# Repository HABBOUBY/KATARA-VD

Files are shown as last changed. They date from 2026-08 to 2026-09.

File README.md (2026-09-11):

<div align="center">

# KATARA-VD

### une mahcine qui ne vend pas mais elle donne

<p align="center">
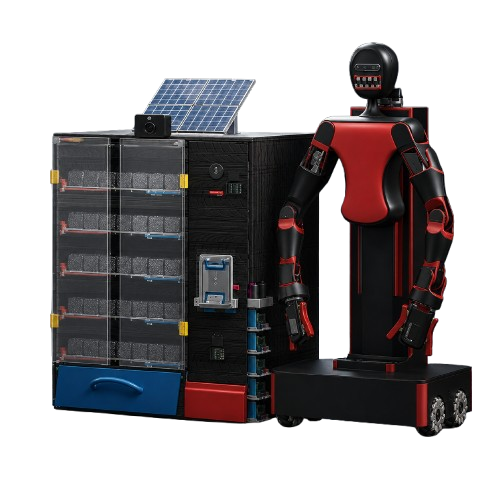
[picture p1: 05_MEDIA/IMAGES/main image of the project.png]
  
</p>

<p align="center">
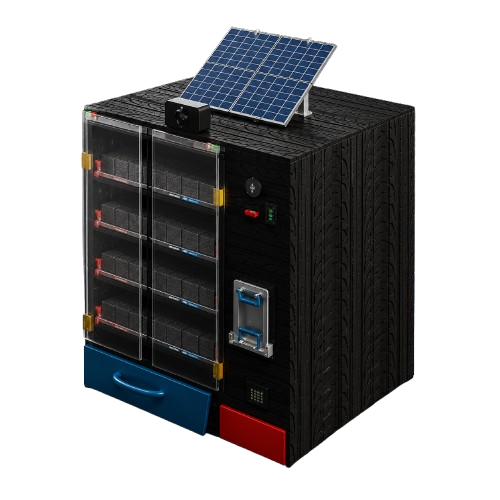
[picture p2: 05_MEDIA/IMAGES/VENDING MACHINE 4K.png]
  
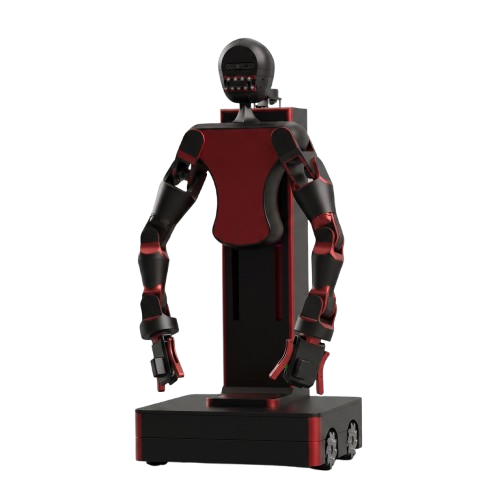
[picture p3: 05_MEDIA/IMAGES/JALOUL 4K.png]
  
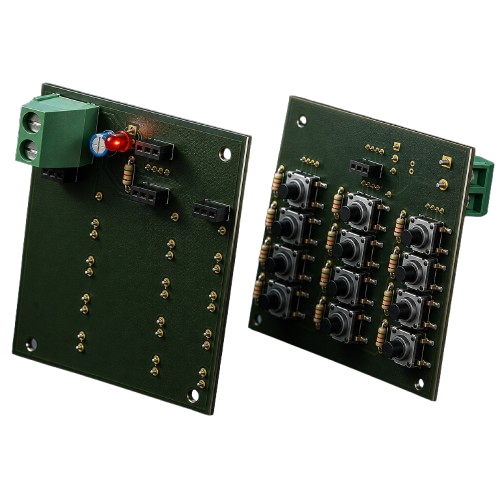
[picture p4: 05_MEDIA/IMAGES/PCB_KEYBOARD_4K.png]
  
</p>










Built by **HABBOUBY EDEM**

</div>

---

## Table of Contents

- [About](#about)
- [Repository Structure](#repository-structure)
- [Scope of This Submission](#scope-of-this-submission)
- [Note on Physical Fabrication](#note-on-physical-fabrication)
- [The Story Behind KATARA-VD](#the-story-behind-katara-vd)
- [The Ecosystem: 2 Systems, 1 Mission](#the-ecosystem-2-systems-1-mission)
- [Vending Machine](#vending-machine)
  - [Part 1 — Skeleton, Shelving & Archimedean Dispensers](#part-1--skeleton-shelving--archimedean-dispensers)
  - [Part 2 — Solar Power & Access Doors](#part-2--solar-power--access-doors)
  - [Part 3 — Prescription Verification System](#part-3--prescription-verification-system)
  - [Part 4 — Coin Dispensing Mechanism ("Giving Money")](#part-4--coin-dispensing-mechanism-giving-money)
  - [Part 5 — Coin Acceptance & Storage](#part-5--coin-acceptance--storage)
  - [Part 6 — Charity Keypad PCB](#part-6--charity-keypad-pcb)
  - [Part 7 — Thermal Sensing & Voice Interaction](#part-7--thermal-sensing--voice-interaction)
- [JALOUL — The Restocking Humanoid](#jaloul--the-restocking-humanoid)
  - [Part 8 — Head & Expression System](#part-8--head--expression-system)
  - [Part 9 — Body & Shoulder Joints](#part-9--body--shoulder-joints)
  - [Part 10 — Arm Completion & 360° Gripper](#part-10--arm-completion--360-gripper)
  - [Part 11 — Mecanum Base & Vertical Lift](#part-11--mecanum-base--vertical-lift)
  - [Part 12 — Frame Reinforcement & LiDAR](#part-12--frame-reinforcement--lidar)
- [The Humanitarian Logic — How the Community Fund Works](#the-humanitarian-logic--how-the-community-fund-works)
- [Electronics & PCB](#electronics--pcb)
- [Materials & Fabrication](#materials--fabrication)
- [Fasteners](#fasteners)
- [CAD Files](#cad-files)
- [Simulations](#simulations)
- [On AI Assistance](#on-ai-assistance)
- [Future Improvements](#future-improvements)
- [License](#license)

---

## About

**Katara-vd** une machine intelligente qui donne au lieu de vendre les médiacaments pour les personnes qui ont besoin . et pour que les riches personnes ont accès à cette mahicne ils doivent payer 2 euro , accompagné d'un huamnoid robot qui permet de remplir le distributeur .

Katara-vd  est le projet principal constitué de deux mini -projet:

-le distributeur: qui a une partie pour les médicaments , de plus , ce distributeur a une partie pour les dons qui a un mécanisme de pousse pour donner de l'argent et une petite pièce pour trier les pièces de monnaie ( seulement accepte les pièces de 2 euro)

-The humanoid robot  , son nom est "JALLUL " son tache est de remplir le distributeur lorsqu'il est vide de médicament 

---

## Repository Structure

```text
KATARA-VD/
│
├── 01_3D/
│   ├── SOLIDWORKS_FILES/
│   │   ├── HUMANOID_ROBOT JALOUL/      
│   │   └── VENDING_MACHINE/            
│   ├── STEP_FILES/
│   │   ├── HUMANOID_ROBOT JALOUL/      
│   │   └── VENDING_MACHINE/         
│   └── STL/
│       ├── HUMANOID_ROBOT JALOUL/      
│       └── VENDING_MACHINE/            
│
├── 02_DXF/
│   └── VENDING_MACHINE/
│
├── 03_PCB_DESIGN/
│   ├── VENDING MACHINE PCB.kicad_sch / .kicad_pcb / .kicad_pro / .kicad_prl
│   └── CARTE ELEC MEC 07.step
│
├── 04_DOCS/
│   └── KATARA-VD_PCB_Components.xlsx   
│   └──WIRING
|
├── 05_MEDIA/
│   ├── IMAGES/
│   │   ├── main image of the project.png
│   │   ├── VENDING MACHINE 4K.png
│   │   ├── JALOUL 4K.png
│   │   ├── JALOUL in different positions.png
│   │   └── PCB_KEYBOARD_4K.png
│   └── SIMULATIONS/
│       ├── mechanism of prescription.gif
│       ├── mechanism of giving money.gif
│       ├── GIF MEC PUSHING THE MONEY INTO THE BOX.gif
│       ├── mechanism for opening and closing door.gif
│       └── translation of the robot on yy' axis.gif
│
├── LICENSE
└── README.md
```

---

## remarque pour la fabrication physique 

malheuresemnt j'ai pas accès à l'impression 3d  pour faire un petit prototype et les composants électriques car ils osnt très chères ( raspberry pi 5 and intel real sense)

Mais "KATARA" est pret pour la mettre en production réelle et le rendre fonctionel ( j'ai mis tous les dossiers nécessaires pour l'impression  3d et le découpe cnc)

- **CNC laser-cut MDF** (`02_DXF/`) 
- **3D-printable STL/STEP** (`01_3D/`) 

-une petite remarque: j'ai fait ce mixage de matière  car il y a des pièces qui sont un peu grande donc il est impossible de l'imprimer avec une printer 3D local

---

## Comment l'idée de KATARA est née
Cette idée est née du hackclub comme il est  "charitable " club , donc j'ai pensé à faire une chose qui a des bienfaits pour tous le monde .

---

# Le distributeur 

## Partie 1 : MEC CiSEAUX

<p align="center">
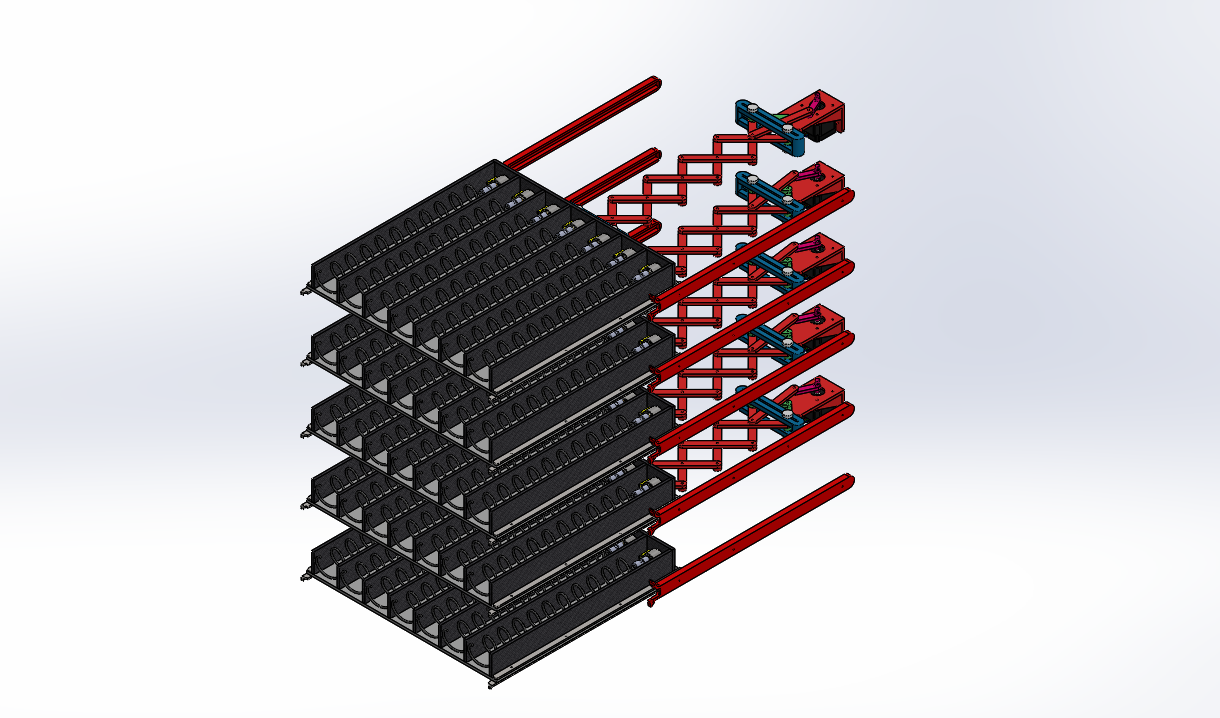
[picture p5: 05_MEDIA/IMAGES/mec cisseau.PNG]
  
</p>

Le distributeur a  5 principaux plateaux qui referment les médicaments .Donc pour que les plateaux soient accessibles à "JALOUL"  , doit avoir un mvt en translation donc le mec de ciseux permet les plateaux de sortir autrement dit mec ciseaux permet de  l'étirement et le raccourcissement des plateaux.Ce mec ciseaux est accompagné avec un stepper A17 de telle façon le mvt en rotation se transforme en translation

---

## Partie 2- panneau solaire et le porte intelligent 

<p align="center">
  
</p>

AU cas ou les batteries sont vide , et n'existe pas du courant donc il le panneau solaire est un alternatif dans ce cas ( qui permet de charger un batterie et cette batterie va etre consommé au cas ou les batteries vides.
De plus , ce distributeur a une porte intelligente qui s'ouvre et se ferme avec deux vérins électriques d'un façon  à transformer le mvt linéaire en mvt rotatif .Et ça a une dualité de fonction le distributeur n'est pas accessibles aux personnes seulement au "JALLOUL"

---

## Part 3 — Scanner et vérifier l'accès pour les médicaments
<p align="center">
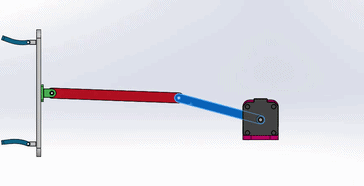
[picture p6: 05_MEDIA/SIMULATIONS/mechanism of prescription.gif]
  
</p>

Pour avoir un accès légal pour le distributeur , doit etre la personne accompagné avec une ordonnance.Cette etapge est guidé avec un mécanisme linéaire avec un stepper nema A 17 qui permet de translater un support qui a intérieument deux aimants magnétiques de telle façon l'ordonnace est attaché au support avec deux fixation que peut la personnes l'ouvrir et le fermer  ( aussi ces deux fixations ont à son intérieur un aimant magnétique de façon une attraction magnétique va etre crée avec le support principal ).Puis un caméra intelreal sense va détecter  le nom du médicament .Et finalement le médicament est poussé avec un spirale ( avec un moteur pas à pas petit ) puis il tombe en faisant une chute libre.

<p align="center">
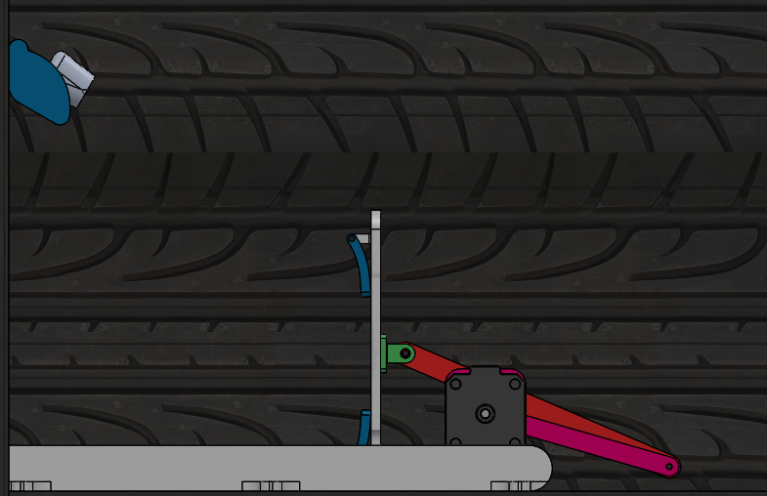
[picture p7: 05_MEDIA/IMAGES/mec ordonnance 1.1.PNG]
  
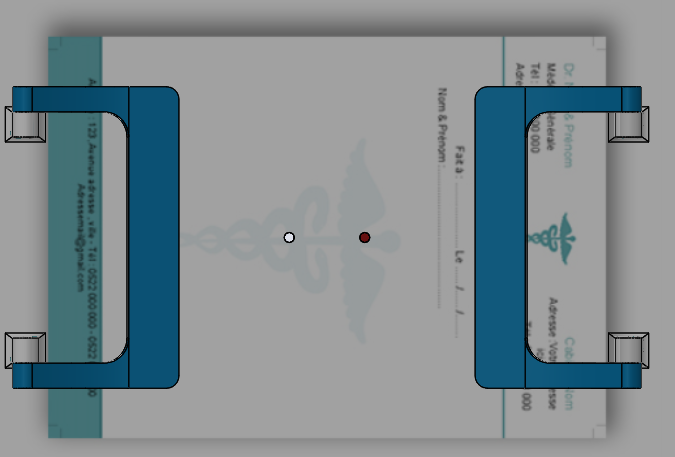
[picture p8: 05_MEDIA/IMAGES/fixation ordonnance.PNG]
  
</p>

*A gauche: le mvt linéaire par le stepper et le scan avec le caméra intelreal sense * 
*A droit : le support de l'ordonnance et ses deux fixations  qui vont  l'attatacher *

---

## Part 4 — système de pousse de l'argent

<p align="center">
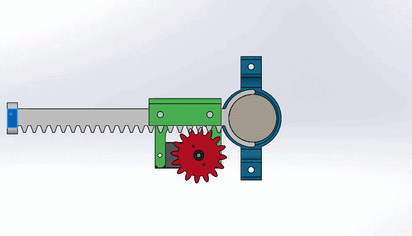
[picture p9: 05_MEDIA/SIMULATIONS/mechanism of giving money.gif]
  
</p>
<p align="center">
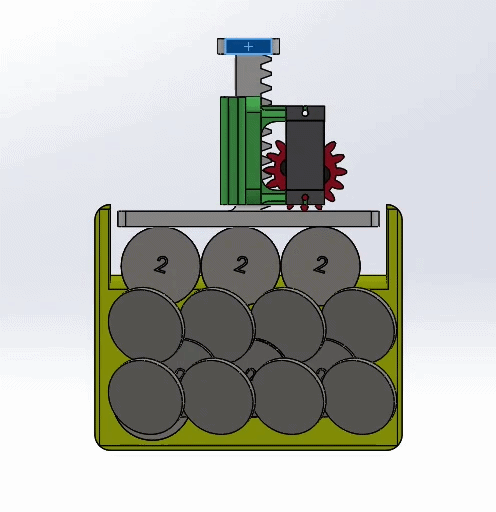
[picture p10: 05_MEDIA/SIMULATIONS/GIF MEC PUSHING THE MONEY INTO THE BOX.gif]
  
</p>

Le premier GIF  montre , le pousse de l'argent pour les donnés aux personnes qui ont besoin 
Le dexième GIF montre aussi le pousse de l'argent mais dans un box , et ce mec est pour conserver les pièces de monnaies que les riches personnes ont donné  dans le boxe  qui sont tombé de la pièce de tri de monnaie 

---

## Part 5 — LA pièce de tri de l'argent 

<p align="center">
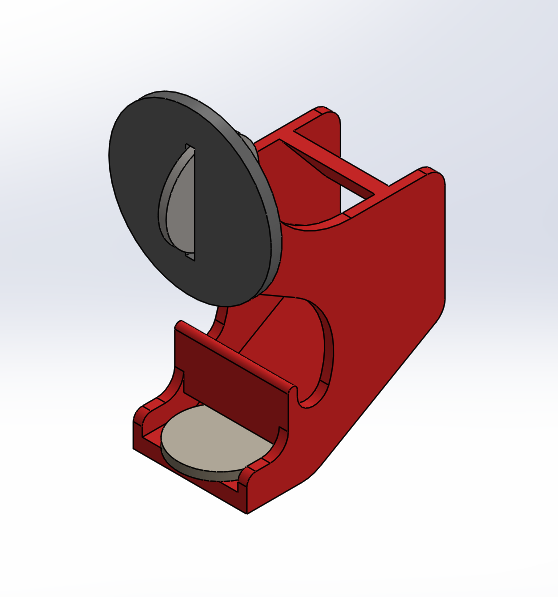
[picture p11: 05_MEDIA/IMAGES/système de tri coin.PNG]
  
</p>

la pièce de monnaie se glisse d'un façon cette pièce permet de trier les pièces , donc comment ??
Cette pièce a un petit mur qui est oblique d'un 30 degré puis il est suivi  d'un trou  de diamètre un peu plus petit du pièce de monnaie du 2 euro donc si la pièce donné est 2euro va etre glissé  et se tombe dans le box  et il y a un capteur IR qui va détcteer qu'elle a tombé.
Si la pièce est plus petite que 2 euro donc elle va tomber au trou et sort et si elle est plus  grande que 2 euro au début il ne peut pas entrer à cette pièce

regardez l'imagez pour mieux comprendre

---

## Part 6 Clavier PCB pour l'identfication

<p align="center">
  
</p>
Chaque personne de la ville ou cette machine est placé a un code  spécifique à lui  , de telle façon le lorsque la personne entre son code il le connait (est ce qu'il a pris 2 euro par jours ou non ? ) ET il y a deux clavier pour les personnes qui ont besoin et son etat financière est  un peu faible et entre les personnes riches . une petite remarque : il existe deux  clavier un peu les dons et un pour les demandes et chaque clavier a aussi un ecran oled
De plus , j'ai fait une petite liste qui renferme tous les composants électriques nécessaires pour réaliser ces claviers

---

## Part 7 — Détection thermique et interaction vocale

Une caméra  infrarouge qui permet de détecter des signes que quelque chose ne va pas de la tristesse ou un état physique  qui demande  une urgence médicale. avec un petit "speaker" intégré qui va répéter des morceaux mp3 pour faire une interaction avec les personnes et le rendre plus dynamique .

---

# JALOUL — the huamnoid robot

## Part 8 — Head & Expression System

<p align="center">
  
</p>

la tête du jaloul a un caméra Intel Realsense pour détecter le trajectoire et l'entrainer sur le remplissage du distributeur et lorsqu'il est vide 
et aussi les places exactes à mettre les médicaments.
Aussi jalloul a une bouche mécanique pour le rendre un peu plus réel accompagné avec un sevro moteur MG95
( the metal gear)
A l'intérieur de sa tête il y a raspberry pi 5 pour l'analyse de données et faire bouger aussi la bouche 

---

## Part 9 — Le corps et les articulations du "Jaloul"

"Jaloul" a 12 articulations ( 6 articulations pour chaque main)

la première articulation est dans l'épaule .Puis la bras supérieur à une articulation de façon que l'axe du chaque articulation est orthogonal  à l'autre.Puis une articulation pour le coude et finalement un pour le poignet et une autre pour les doigts .

ces articulations sont suffisantes pour faire les tâches nécessaires 

### le box du médicament 
<p align="center">
  medication-tray-isometric-view png
  medication-tray-spacing-topview png
</p>

puisque "JALOUL" a un gripper qui ne peut pas entrer  entre les boxes du médicament  , de telle façon j'ai on va mettre les médicaments espacés pour que jalloul peut les porter avec ses deux "gripper"

## Part 11 — le mvt vertical du jaloul

<p align="center">
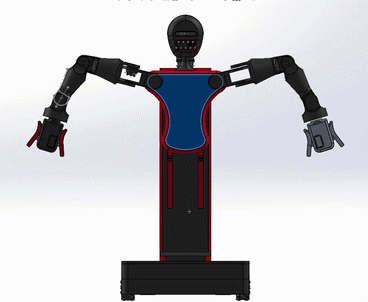
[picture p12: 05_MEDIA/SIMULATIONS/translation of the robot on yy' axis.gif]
  
</p>
jaloul  a un mvt vertical grace à un système vis et écrous pour le donner l'accès au tous éatges du distributeur 
ce mvt lineàire est dû à un mvt rotatif d'un moteur stepper nema A17  avec un  accouplement entre le vis et l'axe du moteur ( juste je vais ajouter un petit remarque que le guidage de vis est accompagné avec un roulement à billes radiales en haut )

aussi jalloul a un capteur lidar qui le permet de tracer son trajectoire et détecter aussi les obstacles pour un mieux mvt

de plus jaloul a une base de 4 roues mecanum qui le donne des choix dans mvt comme ça(↑↓←→ )

---

## Electronics & PCB

- **Raspberry Pi 5** — analyse de données
- 
- **Arduino Mega 2560** —carte de commande 
- **Custom KiCad PCB** - le clavier qui permet de connaître chacun avec son identifiant 

voire les composants électriques d'amazon: 
[`04_DOCS/KATARA-VD_PCB_Components.xlsx`](04_DOCS/KATARA-VD_PCB_Components.xlsx).

---

## Materials & Fabrication

| Part type | Material | Fabrication |
|---|---|---|
| Large flat panels (walls, base, shelves) | MDF | CNC laser cutting (`02_DXF/`) |
| Mechanisms & structural parts | ABS | FDM 3D printing |
| Covers & lightweight parts | PLA | FDM 3D printing |

| Setting | Value |
|---|---|
| Layer Height | 0.20 mm |
| Nozzle | 0.4 mm |
| Infill | 20% |
| Walls | 3 |
| Supports | Only where needed |

---

## Fasteners

| Screw | Length | Quantity |
|---|---:|---:|
| M3 | 20 mm | 40 |
| M3 | 30 mm | 40 |

---

## Simulations

<table>
<tr>
<td width="33%" align="center">

**Prescription mechanism**



Rotary-to-linear extension that presents the prescription to the RealSense camera.

</td>
<td width="33%" align="center">

**Giving money mechanism**



Rack-and-pinion coin ejection, sized to a 1-euro coin.

</td>
<td width="33%" align="center">

**Coin storage**



Donated coins pushed securely into the storage box.

</td>
</tr>
<tr>
<td width="33%" align="center">

**Door actuation**

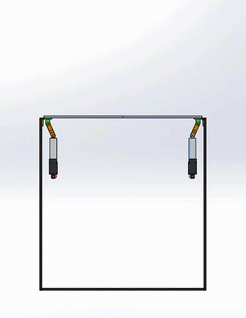
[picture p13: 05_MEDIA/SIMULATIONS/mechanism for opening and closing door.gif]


Dual-actuator, hinge-guided access doors.

</td>
<td width="33%" align="center">

**JALOUL — Y-axis translation**



The backpack lift traveling along the Y-Y′ axis via lead screw.

</td>
<td width="33%" align="center">

**JALOUL — arm reach**

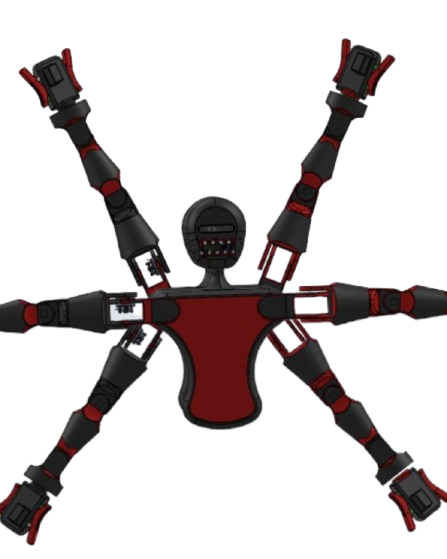
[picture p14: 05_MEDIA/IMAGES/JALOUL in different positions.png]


Both arms swept across multiple positions, showing the range unlocked by the extra joints.

</td>
</tr>
</table>

---

##ce que je peux faire dans le future 

-Faire un assemblage et imprimer les pièces  pour faire un petit prototype 
-ajoutez un drone pour transporter les médicaments du l'usine lorsque le stockage est vide

---

## License

**MIT License**.

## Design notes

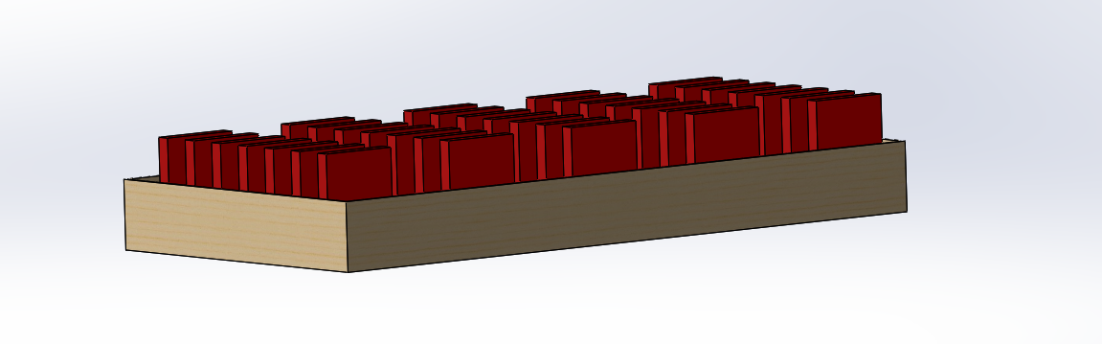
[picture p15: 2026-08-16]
05_MEDIA/IMAGES/medication-tray-isometric-view.png.PNG

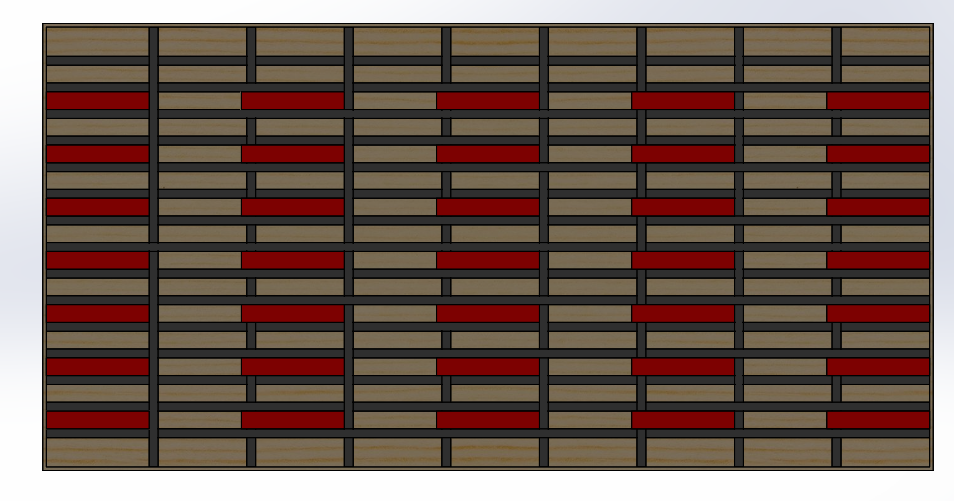
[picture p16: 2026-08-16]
05_MEDIA/IMAGES/medication-tray-spacing-topview.png.PNG

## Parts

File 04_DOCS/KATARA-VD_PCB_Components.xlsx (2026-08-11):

KATARA-VD — PCB Electronic Components (Keypad / Charity Module)
Component list for the charity keypad PCB — quantities, specs, and Amazon sourcing links
N° | Component | Quantity | Characteristics / Value | Remarks | Amazon Link | Unit
1 | Push Button (Tactile Switch) | 12 | 6x6mm, 4-pin THT, momentary SPST | Used for the keypad digits/entries on the charity donation interface. | View on Amazon (https://www.amazon.com/6x6mm-Tactile-Button-Micro-Switch/dp/B0F7FPCMCF) | pcs
2 | Resistor (Pull-down, for push buttons) | 12 | 10 kΩ, 1/4W, ±1% metal film | One per push button, used as pull-down/pull-up resistor on each digital input pin. | View on Amazon (https://www.amazon.com/Resistor-Resistors-Assortment-Breadboard-Electronics/dp/B0F4P352BB) | pcs
3 | Pin Socket Header (4-pin) | 5 | 2.54mm pitch, single row, 4-position female header | 5 separate 4-pin blocks — used as connectors/expansion headers on the PCB. | View on Amazon (https://www.amazon.com/Female-Headers-2-54mm-Single-Connector/dp/B08T5S54C5) | blocks
4 | Screw Terminal Block (01x02) | 1 | 2-pin, 5.08mm pitch, PCB mount | Power/signal input connector for external wiring. | View on Amazon (https://www.amazon.com/Terminal-Arduino-Electronics-Industrial-Control/dp/B0GMHFBW34) | pcs
5 | Capacitor (Decoupling) | 1 | 100 nF (0.1 µF), ceramic disc | Decoupling/filtering capacitor near the microcontroller supply pins. | View on Amazon (https://www.amazon.com/100PCS-100nf-Ceramic-Capacitor-Capacitors/dp/B0H6MJXNKM) | pcs
6 | Resistor (LED current-limiting) | 1 | 220 Ω, 1/4W | Current-limiting resistor in series with the OLED status LED / indicator. | View on Amazon (https://www.amazon.com/Resistor-Resistors-Assortment-Breadboard-Electronics/dp/B0F4P352BB) | pcs
7 | LED | 1 | 5mm, standard round, THT | Status/indicator LED for the charity keypad module. | View on Amazon (https://www.amazon.com/Diffused-Lighting-Electronics-Components-Emitting/dp/B01C3ZZT2I) | pcs
 | TOTAL COMPONENTS | 33
Note: Resistor values (10 kΩ pull-down, 220 Ω current-limiting) are recommended standard values — adjust based on final PCB testing and MCU logic level (3.3V/5V).
Links point to representative Amazon listings for sourcing reference; verify specs/pricing before ordering.

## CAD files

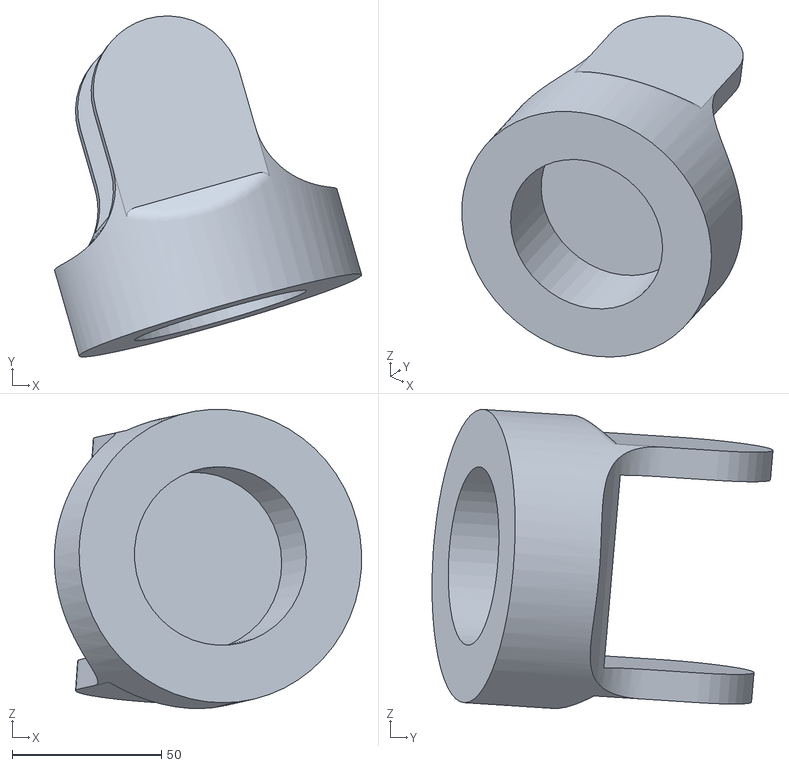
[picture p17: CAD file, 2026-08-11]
01_3D/STL/HUMANOID_ROBOT JALOUL/total assembly of jaloul - assemblt jaloul main two-1 link 4-1.STL
103.0 x 114.4 x 100.3

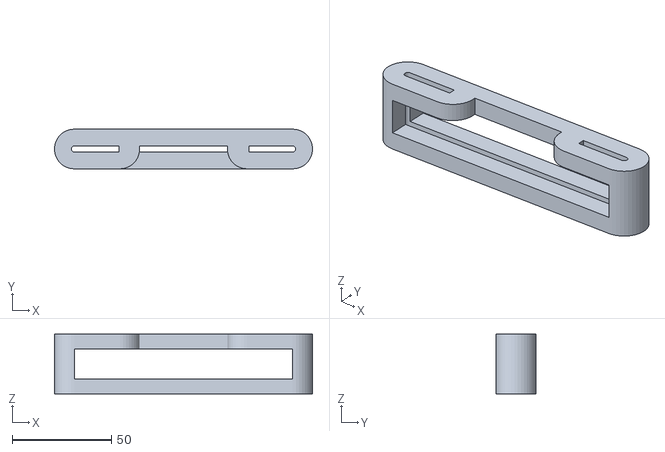
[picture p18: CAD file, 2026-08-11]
01_3D/STL/VENDING_MACHINE/assembly mec cisseau - guidage cisseau-1.STL
129.9 x 20.0 x 30.0

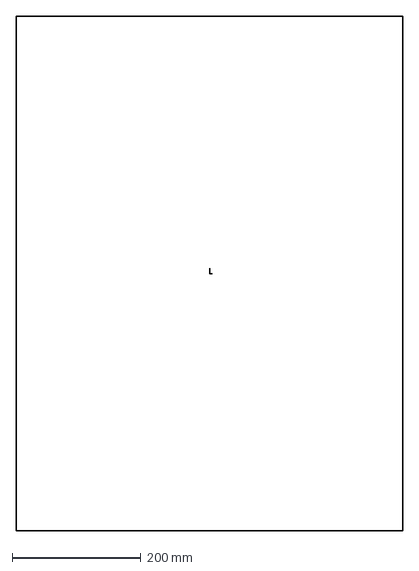
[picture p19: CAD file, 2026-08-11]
02_DXF/VENDING_MACHINE/mur vending machine main one.DXF
600.0 x 800.0 mm

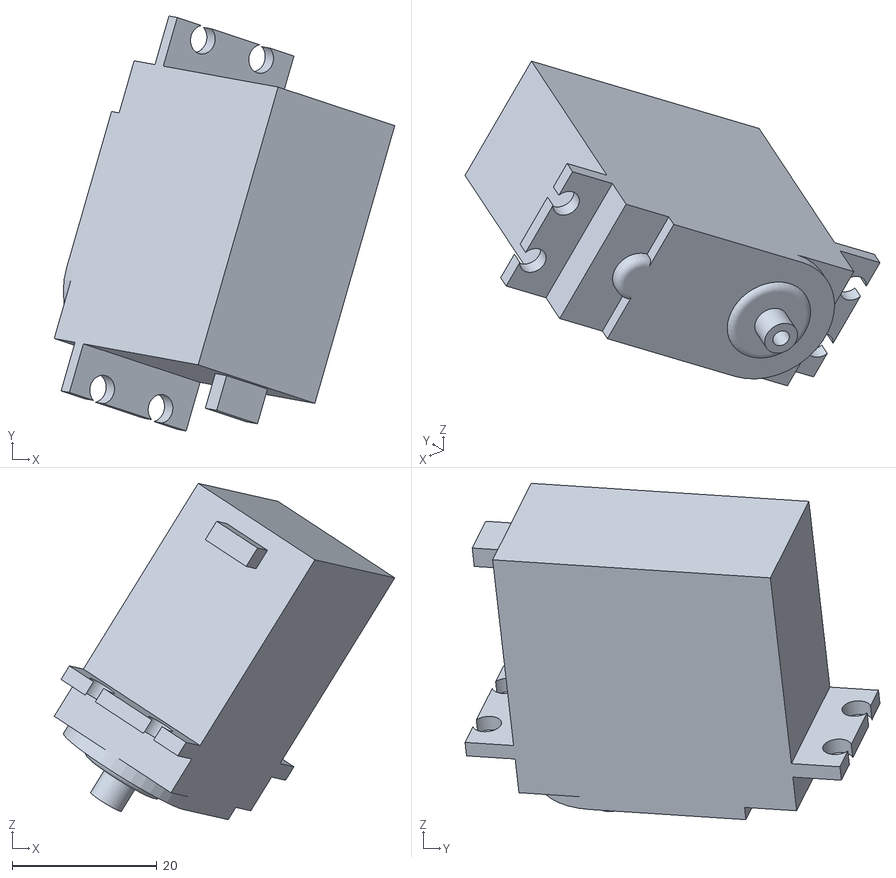
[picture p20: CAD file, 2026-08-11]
01_3D/STL/HUMANOID_ROBOT JALOUL/total assembly of jaloul - assemblt jaloul main two-1 Symétrieassembly gripper jalloul-3 Symétrieservo Assem-1 Symétrieservo strong junk 2-1.STL
47.1 x 57.3 x 46.5

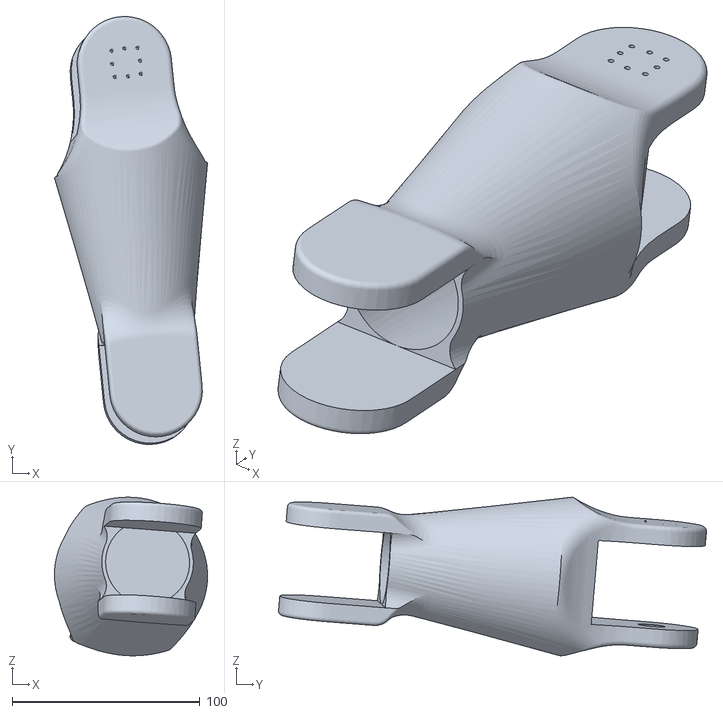
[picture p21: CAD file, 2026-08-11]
01_3D/STL/HUMANOID_ROBOT JALOUL/total assembly of jaloul - assemblt jaloul main two-1 LINK 3 JALOUL-1.STL
81.6 x 228.1 x 84.5

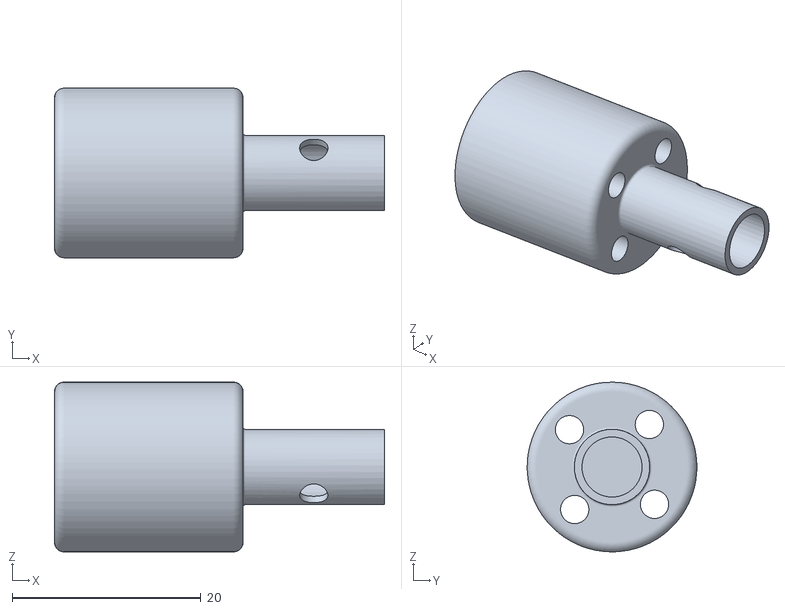
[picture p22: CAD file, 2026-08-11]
01_3D/STL/HUMANOID_ROBOT JALOUL/total assembly of jaloul - assembly bas robot jlayla-1 accouplement stpper with mecanum wheel-1.STL
35.0 x 18.0 x 18.0

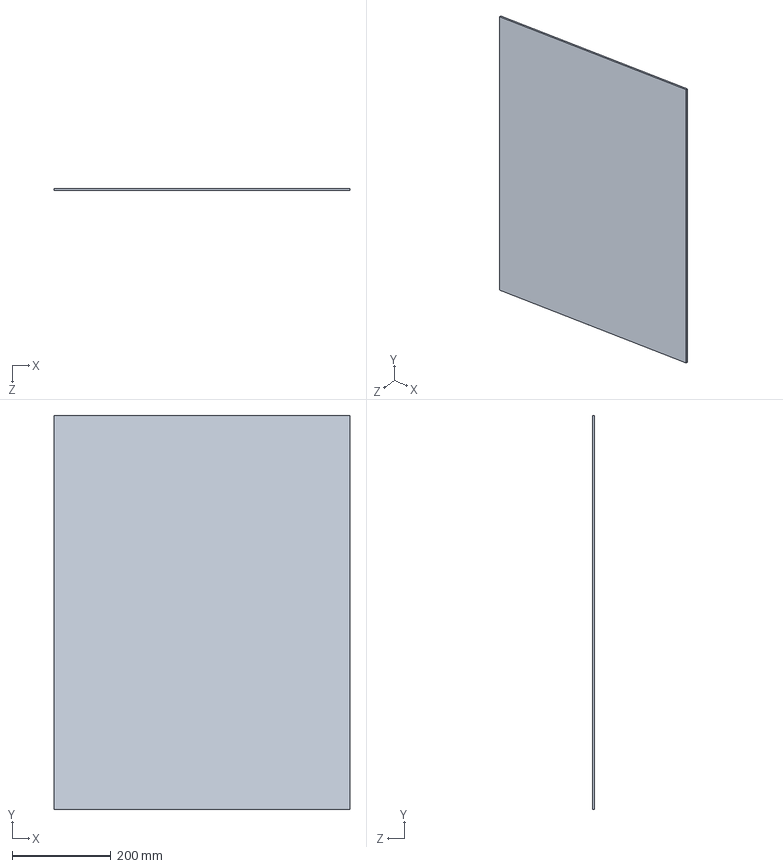
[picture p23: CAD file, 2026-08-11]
01_3D/SOLIDWORKS_FILES/VENDING_MACHINE/mur vending machine main one.SLDPRT
600.0 x 800.0 x 5.00 mm

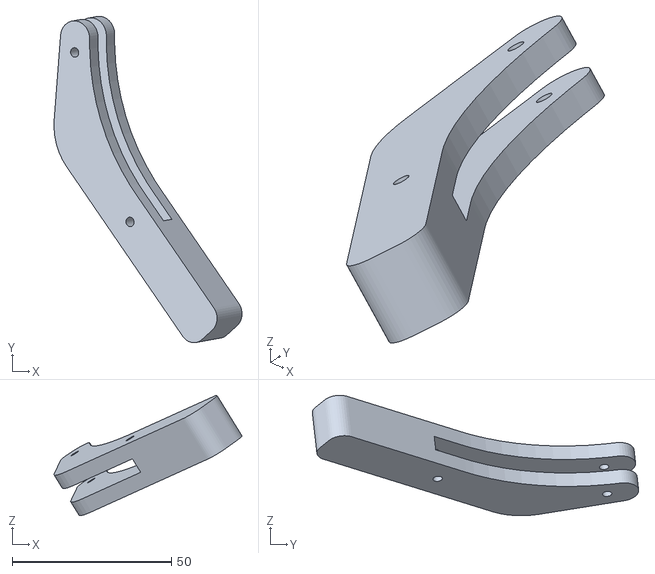
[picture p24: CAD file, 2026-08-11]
01_3D/STL/HUMANOID_ROBOT JALOUL/total assembly of jaloul - assemblt jaloul main two-1 assembly gripper jalloul-1 yed jaloul-1.STL
59.1 x 102.6 x 37.8

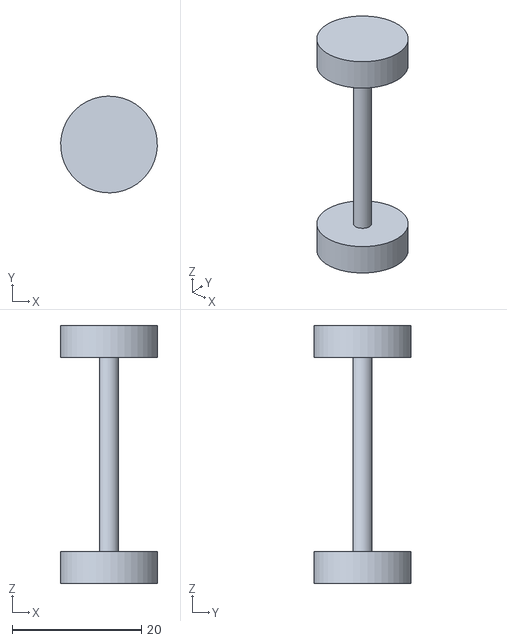
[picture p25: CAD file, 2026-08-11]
01_3D/STL/VENDING_MACHINE/assembly mec cisseau - roue guidage-1.STL
15.0 x 15.0 x 40.0

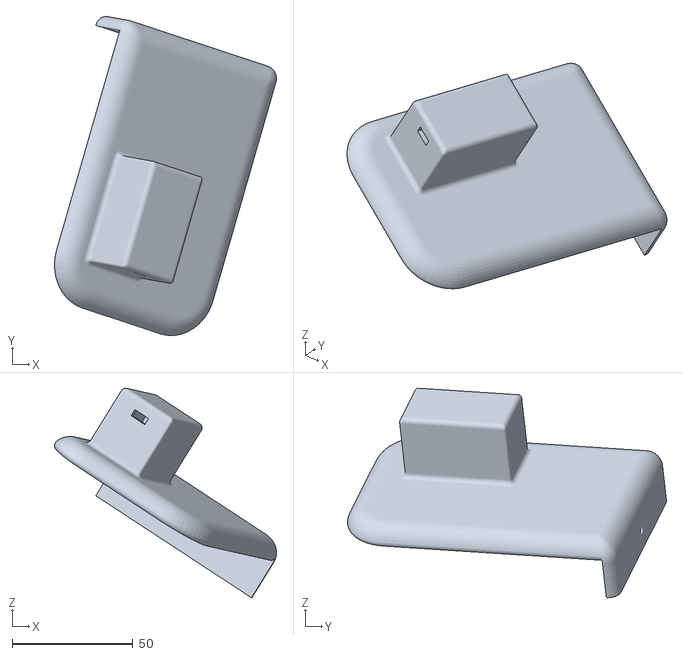
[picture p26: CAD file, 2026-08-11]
01_3D/STL/HUMANOID_ROBOT JALOUL/total assembly of jaloul - assemblt jaloul main two-1 Symétrieassembly gripper jalloul-3 SymétrieBASE GRIPPER JALLOUL-1.STL
92.0 x 132.2 x 86.8

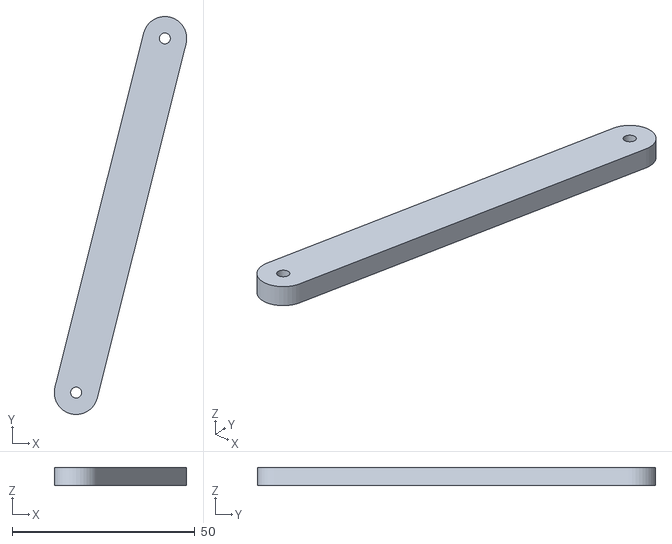
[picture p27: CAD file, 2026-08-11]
01_3D/STL/VENDING_MACHINE/assembly mec cisseau - bras motrice bdiha maak hheeeh-1.STL
36.3 x 109.0 x 5.00

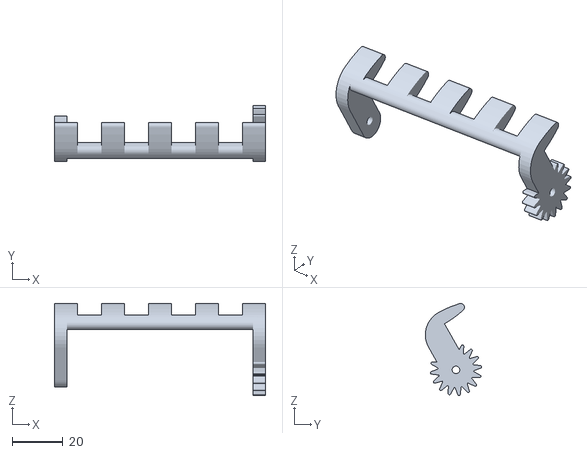
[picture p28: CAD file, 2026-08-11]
01_3D/STL/HUMANOID_ROBOT JALOUL/total assembly of jaloul - assemblt jaloul main two-1 assembly head of jaloul-1 dents du jaloul-1.STL
83.0 x 22.2 x 36.2

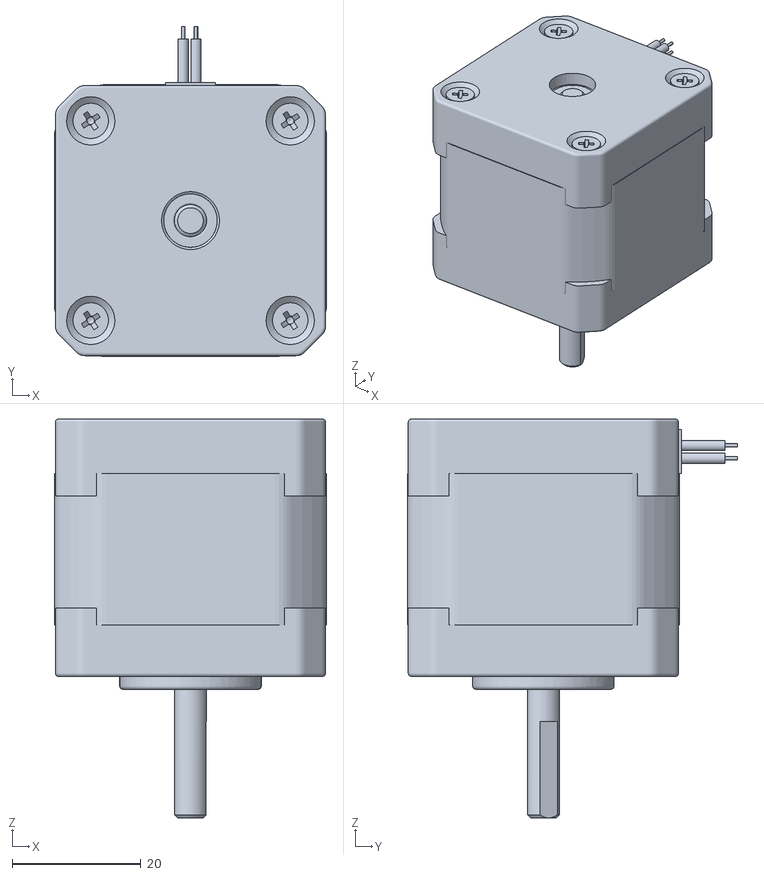
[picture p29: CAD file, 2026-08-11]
01_3D/STL/VENDING_MACHINE/assembly mec cisseau - 17HM15-0904S-1.STL
42.3 x 51.4 x 62.0

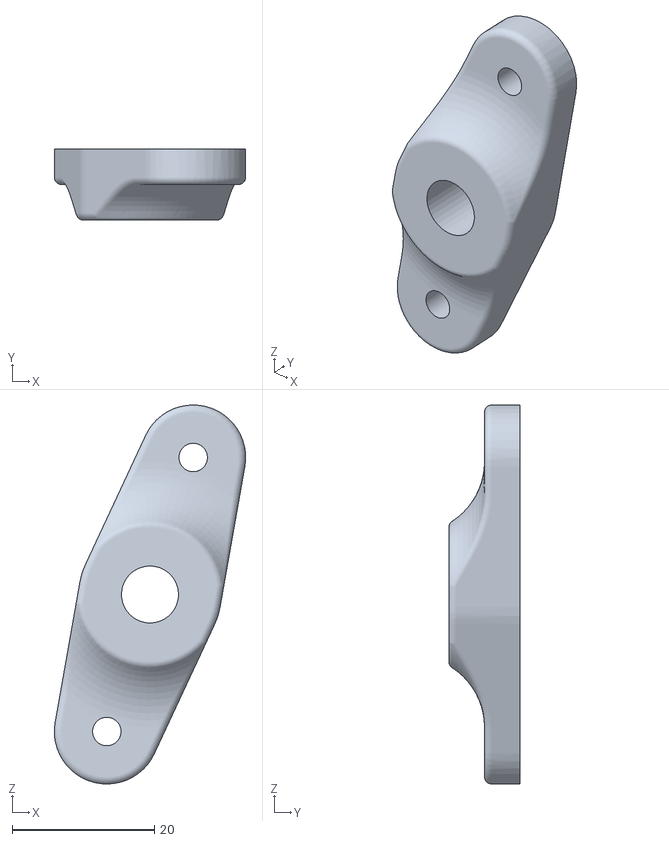
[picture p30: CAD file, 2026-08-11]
01_3D/STL/HUMANOID_ROBOT JALOUL/total assembly of jaloul - pièce de fixation-3.STL
26.9 x 10.0 x 53.2

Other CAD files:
01_3D/STL/VENDING_MACHINE/assembly mec cisseau - bras mère mec cisseau-6.STL
01_3D/STL/HUMANOID_ROBOT JALOUL/total assembly of jaloul - assemblt jaloul main two-1 assembly gripper jalloul-1 Symétriepignon jlayla-3.STL
01_3D/STL/VENDING_MACHINE/assembly mec cisseau - bras mère mec cisseau-1.STL
01_3D/STL/HUMANOID_ROBOT JALOUL/total assembly of jaloul - assemblt jaloul main two-1 assembly head of jaloul-1 M90S_ali.step-1 etiquette.step-1.STL
01_3D/SOLIDWORKS_FILES/HUMANOID_ROBOT JALOUL/BASE GRIPPER JALLOUL.SLDPRT
01_3D/SOLIDWORKS_FILES/HUMANOID_ROBOT JALOUL/BASE ROBOT JALOUL.SLDPRT
01_3D/SOLIDWORKS_FILES/HUMANOID_ROBOT JALOUL/LINK 3 JALOUL.SLDPRT
01_3D/SOLIDWORKS_FILES/HUMANOID_ROBOT JALOUL/LMH8UU.SLDPRT
01_3D/SOLIDWORKS_FILES/HUMANOID_ROBOT JALOUL/LeadScrew Nut 8mm x 2mmPitch.SLDPRT
01_3D/SOLIDWORKS_FILES/HUMANOID_ROBOT JALOUL/MG90S_arm01.step
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

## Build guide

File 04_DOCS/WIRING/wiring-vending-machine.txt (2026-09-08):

====================================================================
KATARA-VD — VENDING MACHINE — WIRING REFERENCE
====================================================================
No dedicated main PCB for this subsystem. The only custom PCB in the
whole project is the charity keypad module (see 03_PCB_DESIGN/).
Everything below lives on perforated prototyping boards , grouped by mechanism to keep wiring runs short.

--------------------------------------------------------------------
1. POWER SOURCES
--------------------------------------------------------------------
- 3x LiPo 3S (11.1V) packs
    -> main power rail for all DRV8825 drivers (VMOT) and actuators
- 1x solar storage battery
    -> charged by the rooftop solar panel
    -> feeds the 11.1V bus automatically whenever the LiPo packs run
       low (diode-OR / auto switch-over between LiPo and solar bank)
- 12V -> 5V buck regulators (mounted on the perfboards)
    -> supply the 5V logic rail: DRV8825 logic (VDD), OLED displays,
       IR sensor, PWM expansion boards, keypad PCB

--------------------------------------------------------------------
2. STEPPER DRIVERS — DRV8825 (41x TOTAL)
--------------------------------------------------------------------
Spread across several perfboards, one cluster per mechanism rather
than a single centralized board:

  - Scissor-lift steppers (NEMA 17)        -> 1x per shelf, 5 shelves
  - Archimedean-screw dispenser steppers   -> grouped per shelf
  - Prescription rotary-to-linear stepper  -> 1x
  - Remaining channels reserved / grouped per mechanism
    (see 04_DOCS/KATARA-VD_PCB_Components.xlsx for the full motor list)

Standard wiring per DRV8825 driver:
  VMOT           -> 11.1V rail (LiPo 3S / solar bank)
  GND (power)    -> common ground
  VDD            -> 5V logic rail
  GND (logic)    -> common ground
  STEP           -> Arduino Mega 2560 digital pin
  DIR            -> Arduino Mega 2560 digital pin
  ENABLE         -> tied low, unless a per-shelf disable line is added
  A1 / A2 / B1 / B2 -> stepper motor coil pairs
  Current limit  -> set via onboard potentiometer, per motor's rating

--------------------------------------------------------------------
3. RASPBERRY PI 5 — VISION & ANALYSIS (x2, ISOLATED SUPPLIES)
--------------------------------------------------------------------
Pi 5 #1 — Infrared & Interaction
  - MLX90640 thermal camera  -> I2C
  - Speaker (via amplifier)  -> I2S or analog audio out
  - Power: own isolated 5V/5A supply, regulated off the 11.1V rail

Pi 5 #2 — Prescription Analysis
  - Intel RealSense D435     -> USB 3.0
  - Power: own isolated 5V/5A supply, regulated off the 11.1V rail

Both Pi 5 boards send their decisions to the Arduino Mega 2560 over
serial/USB; the Mega handles all actuator/motor timing.

--------------------------------------------------------------------
4. SERVO CONTROL — PWM EXPANSION BOARDS (x3)
--------------------------------------------------------------------
3x 16-channel PWM expansion boards (PCA9685-type), addressed over I2C
from the Arduino Mega 2560:

  Board 1 -> Prescription arm servos + magnetic-mount servos
  Board 2 -> Coin dispensing (rack & pinion) + lock/unlock door servo
  Board 3 -> Door actuators (verins) + spare channels

Each board:
  VCC (logic)      -> 5V logic rail
  V+ (servo power) -> 5V logic rail (separate 5V servo rail if current
                       draw requires it)
  GND              -> common ground
  SDA / SCL        -> Arduino Mega 2560 I2C bus (unique address per
                       board via address pins)

--------------------------------------------------------------------
5. SENSORS & INTERFACE
--------------------------------------------------------------------
  - IR sensor (coin acceptance)   -> Arduino Mega 2560 digital input
  - Coin sorter mechanism         -> mechanical only, no electronics
  - OLED displays (x2, 1/keypad)  -> I2C, distinct addresses
  - Charity keypad PCB            -> button matrix to Mega digital
                                      inputs + OLED on shared I2C bus

--------------------------------------------------------------------
6. SOLAR / CHARGE PATH
--------------------------------------------------------------------
  Solar panel -> charge controller -> solar storage battery
              -> 11.1V bus (shared with the 3x LiPo 3S packs via
                 diode-OR / automatic switch-over)

--------------------------------------------------------------------
NOTES
--------------------------------------------------------------------
- No custom PCB for the main system: DRV8825 clusters and 12->5V
  regulators live on perfboards, grouped by mechanism.
- The only custom PCB is the charity keypad module (03_PCB_DESIGN/).
- Common ground must be shared across every perfboard, both Pi 5
  units, the Arduino Mega 2560, and the LiPo/solar power path.
- Exact pin assignments for the Arduino Mega 2560 are firmware-side
  and will be documented once control code is written (see README ->
  Future Improvements).

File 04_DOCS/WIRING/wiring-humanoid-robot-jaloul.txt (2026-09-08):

====================================================================
KATARA-VD — JALOUL (HUMANOID ROBOT) — WIRING REFERENCE
====================================================================
No dedicated PCB for JALOUL either. Same approach as the vending
machine: DRV8825 driver(s) and 5V regulation live on a perforated
prototyping board .

--------------------------------------------------------------------
1. POWER SOURCES
--------------------------------------------------------------------
- 2x LiPo 3S (11.1V) packs:
    Pack 1 -> Navigation systems (RPLiDAR, sensors, logic-side
              electronics)
    Pack 2 -> Joint actuation & Y-Y' translation system (all servos +
              all steppers: arms, gripper, mecanum base, backpack lift)
- Raspberry Pi 5:
    -> own dedicated, isolated power bank — never shares a rail with
       Pack 1 or Pack 2, to protect it from motor noise/brownouts
- 5V logic rail:
    -> regulated off Pack 2, feeds DRV8825 logic and low-power
       peripherals

--------------------------------------------------------------------
2. STEPPER DRIVERS — DRV8825, 5V LOGIC
--------------------------------------------------------------------
DRV8825 driver(s) for the NEMA 17 stepper(s), mounted on the perfboard:
  VMOT           -> 11.1V rail (Pack 2)
  GND (power)    -> common ground
  VDD            -> 5V logic rail
  GND (logic)    -> common ground
  STEP           -> control board digital pin
  DIR            -> control board digital pin
  A1 / A2 / B1 / B2 -> stepper coil pairs
  Current limit  -> set via onboard potentiometer

Note: the mecanum base (4x NEMA 23) and the Y-Y' backpack lift
(1x NEMA 23) run on their own higher-current drivers, wired the same
way but sized for NEMA 23 current draw — check
04_DOCS/KATARA-VD_PCB_Components.xlsx for driver ratings per motor.

--------------------------------------------------------------------
3. RASPBERRY PI 5 — VISION & NAVIGATION
--------------------------------------------------------------------
  - Intel RealSense D435 -> USB 3.0, head-mounted vision
  - RPLiDAR              -> USB/UART, obstacle detection & mapping
  - Power: dedicated power bank, isolated from Pack 1 and Pack 2
  - Sends motion/joint commands to the onboard control board over
    serial/USB

--------------------------------------------------------------------
4. SERVO CONTROL
--------------------------------------------------------------------
  - MG90S servos -> mouth mechanism + smaller joints
  - MG995 servos -> gripper, one per arm
  - Power: 5V logic rail (Pack 2), common ground with the control board

--------------------------------------------------------------------
5. POWER SPLIT LOGIC
--------------------------------------------------------------------
  Pack 1 (Navigation):    RPLiDAR + navigation sensors + logic
  Pack 2 (Joints & Y-Y'): all servos + all steppers (arms, gripper,
                           mecanum base, backpack lift)
  Pi 5 power bank:        isolated — never shares a rail with either
                           LiPo pack

--------------------------------------------------------------------
NOTES
--------------------------------------------------------------------
- No custom PCB for JALOUL: DRV8825 driver(s) and 5V regulation live
  on a perfboard, same approach as the vending machine.
- Common ground must be shared across the perfboard, the Raspberry
  Pi 5, and both LiPo packs — except where isolation is intentional
  (the Pi 5 power bank).
- NEMA 23 current draw (base + lift) is significantly higher than
  NEMA 17 — size wiring gauge and driver heatsinking accordingly.
- Exact control-board pin assignments are firmware-side and will be
  documented once control code is written (see README -> Future
  Improvements).

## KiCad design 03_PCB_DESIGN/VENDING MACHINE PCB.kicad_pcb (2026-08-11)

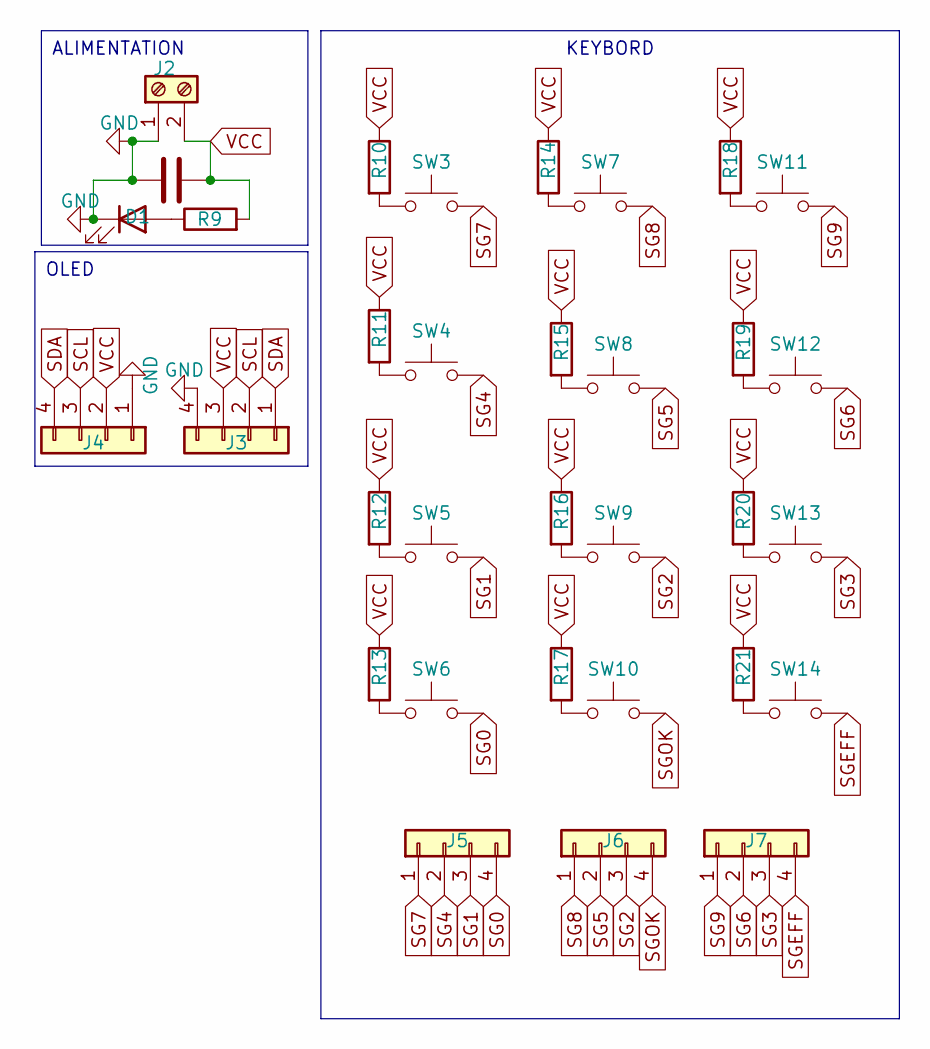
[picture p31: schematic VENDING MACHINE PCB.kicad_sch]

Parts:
C1: C; CP_Radial_D4.0mm_P1.50mm
D1: LED; LED_D3.0mm
J2: Screw_Terminal_01x02; TerminalBlock_Phoenix_MKDS-1,5-2_1x02_P5.00mm_Horizontal
J3, J4, J5, J6, J7: Conn_01x04; PinSocket_1x04_P1.27mm_Vertical
R9, R10, R11, R12, R13, R14, R15, R16, R17, R18, R19, R20, R21: R; R_Axial_DIN0204_L3.6mm_D1.6mm_P5.08mm_Horizontal
SW3, SW4, SW5, SW6, SW7, SW8, SW9, SW10, SW11, SW12, SW13, SW14: SW_Push; SW_Push_1P1T_NO_CK_KSC6xxG

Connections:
GND: C1.2, D1.1 (K), J2.1, J3.4, J4.1
unnamed: D1.2 (A), R9.1
unnamed: R10.2, SW3.1
unnamed: R11.2, SW4.1
unnamed: R12.2, SW5.1
unnamed: R13.2, SW6.1
unnamed: R14.2, SW7.1
unnamed: R15.2, SW8.1
unnamed: R16.2, SW9.1
unnamed: R17.2, SW10.1
unnamed: R18.2, SW11.1
unnamed: R19.2, SW12.1
unnamed: R20.2, SW13.1
unnamed: R21.2, SW14.1
SCL: J3.2, J4.3
SDA: J3.1, J4.4
SG0: J5.4, SW6.2
SG1: J5.3, SW5.2
SG2: J6.3, SW9.2
SG3: J7.3, SW13.2
SG4: J5.2, SW4.2
SG5: J6.2, SW8.2
SG6: J7.2, SW12.2
SG7: J5.1, SW3.2
SG8: J6.1, SW7.2
SG9: J7.1, SW11.2
SGEFF: J7.4, SW14.2
SGOK: J6.4, SW10.2
VCC: C1.1, J2.2, J3.3, J4.2, R9.2, R10.1, R11.1, R12.1, R13.1, R14.1, R15.1, R16.1, R17.1, R18.1, R19.1, R20.1, R21.1

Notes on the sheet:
ALIMENTATION
KEYBORD
OLED

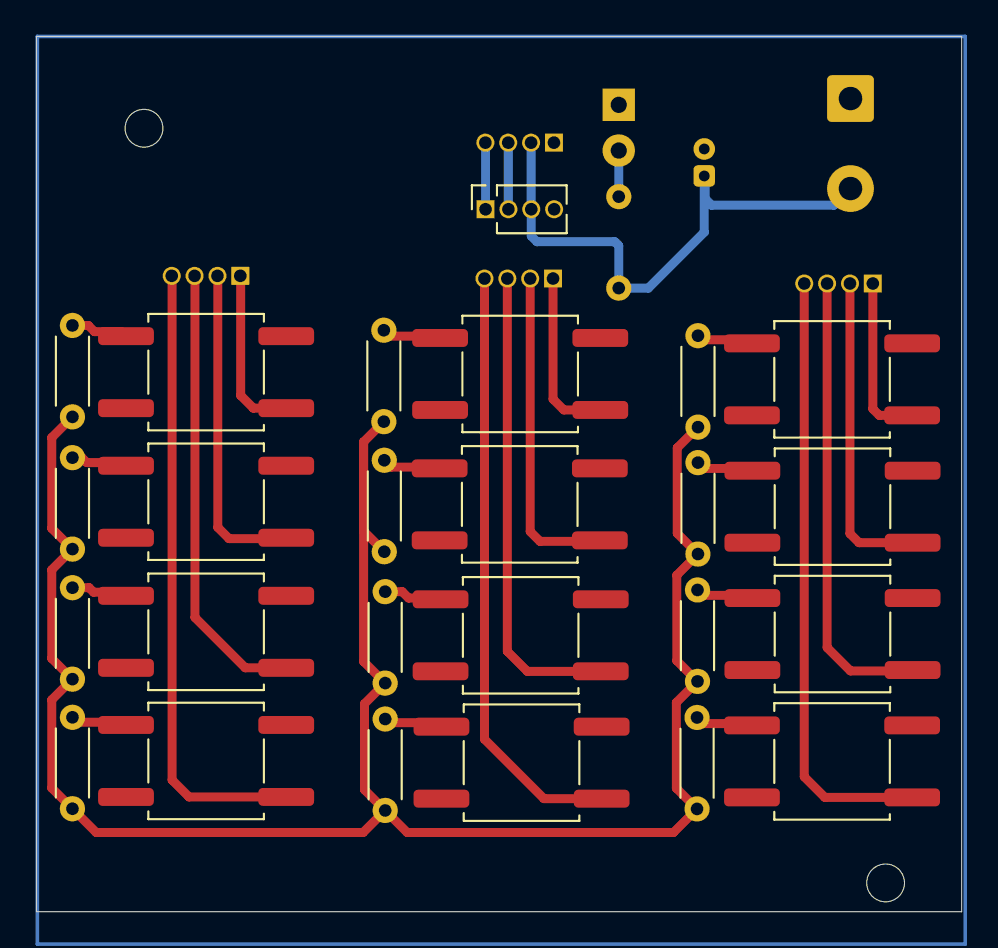
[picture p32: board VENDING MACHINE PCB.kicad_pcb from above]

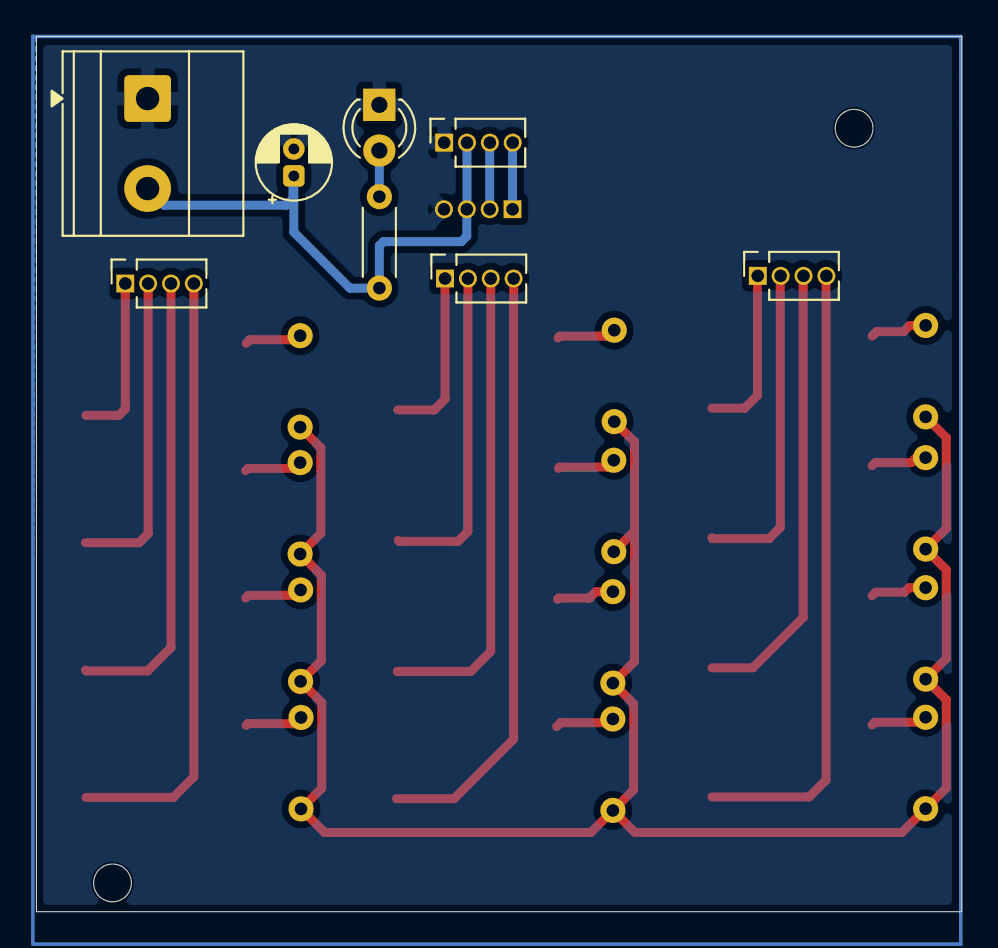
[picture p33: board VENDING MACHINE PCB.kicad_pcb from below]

Board: 2 copper layers, 51.4 x 48.6 mm, 33 parts (8 on the bottom side), 29 nets.

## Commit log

2026-08-11 go on
    [CARTE ELEC MEC 07.step, KATARA-VD_PCB_Components.xlsx, VENDING MACHINE PCB.kicad_pcb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]
2026-09-11 Revise descriptions in README.md to French
    Updated French translations for the rotary-to-linear stepper mechanism description.
